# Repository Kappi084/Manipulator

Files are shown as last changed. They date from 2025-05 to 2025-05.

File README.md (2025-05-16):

# Project Background
This project was developed as part of a school project at KTLA (6/7KBMB 2024/25) — a technical school specializing in Mechanical Engineering & Automation Technology.

The manipulator serves as a platform for mechanical engineering students to focus on:

- Learning and applying mechanical design principles
- Improving skills in statics, kinematics, and CAD modeling
- Collaborating across disciplines (mechanical + software)

By separating the complexity of motion programming from the mechanical design, the project allows students to dive deeper into the core engineering concepts without getting blocked by the electronics or software side.

The challenge was to create a universal manipulator platform that can be used for various motion-based systems. T
To solve this, the idea was to build a modular, easy-to-use motion control system — both electrical and in software.

Design Philosophy
The goal of this project was to create a system that is:

✅ Affordable
  Using standard components and easy-to-source materials.
  
✅ Simple to assemble
  Clear CAD files and pre-configured print settings make the system easy to build.
  
✅ Flexible and reusable
  Designed to work across different types of motion systems (e.g., CoreXY, Cartesian, SCARA) with minimal changes.
  
✅ Beginner-friendly software integration
  The controller is programmed in a way that someone without prior coding experience can:

⚙️ Note: The system must be calibrated and configured first. After that, the software can be extended or customized with basic programming skills.

⚙️ Extendable for advanced users
  With just a bit more programming knowledge, the control library can be easily adapted for:

Future Ideas:
- Different kinematics (CoreXY, Delta, etc.)
- External control via digital/analog inputs and outputs
- Different Controller

# Manipulator Overview
This Github-Page is splitted in 3 parts:
- Mecanic
- Electric
- Software

The manipulator shown below features a working range of approximately 250 mm in the X-axis and 750 mm in the Y-axis.

We have implemented a CoreXY kinematic system for this build. CoreXY is a motion architecture commonly used in high-performance 2D positioning systems (e.g., 3D printers, CNC machines) due to its speed, precision, and mechanical efficiency. A detailed describtion you can find in the CAD folder.

Schnittstellenbeschreibung-Kinematic drawio

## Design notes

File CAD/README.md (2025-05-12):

# Mechanical Design (CAD)
This section explains how the manipulator is built and the reasons behind the mechanical design decisions.

If you want to build your own version or take inspiration from this project, all CAD files are available directly on this GitHub repository.
For 3D printing, all relevant STL files — including recommended printer profiles — are also published on MakerWorld:

🔗 MakerWorld – Project Files

# Why CoreXY?
CoreXY offers several advantages compared to traditional Cartesian setups:

- Lightweight X-axis assembly Since both stepper motors are stationary, only the toolhead moves, which significantly reduces the moving mass and allows for faster acceleration.

- High-speed movement The reduced inertia of the moving parts enables rapid and precise movement, ideal for applications requiring speed and accuracy.

- Sturdy and space-efficient design CoreXY allows the motors to be placed on the frame, improving rigidity and making the design more compact.

- Popular and well-documented CoreXY is widely adopted and supported by many firmware platforms like Klipper and Marlin.

🔗 Learn more about CoreXY here: https://corexy.com


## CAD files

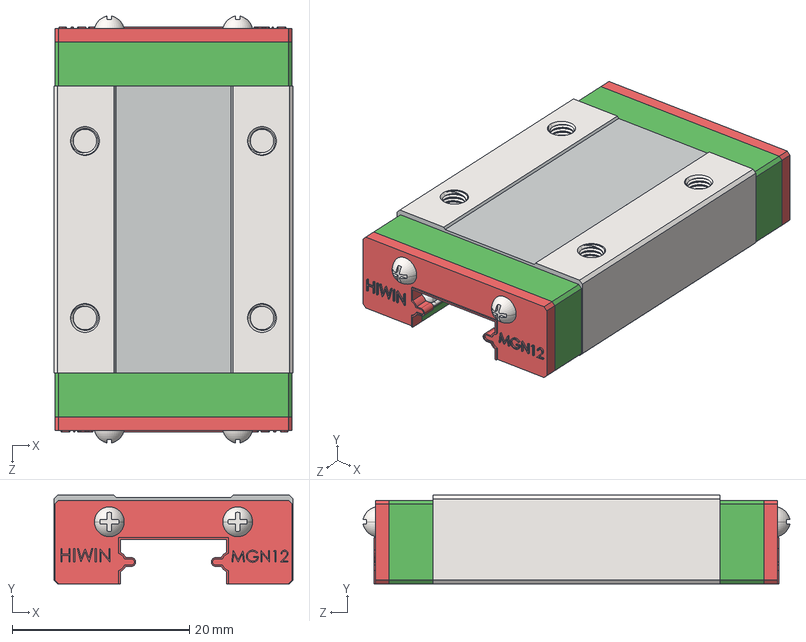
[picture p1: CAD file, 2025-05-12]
CAD/01_StandaradParts/Linear-Rail/Sledge/MGN12H.STEP
27.0 x 10.0 x 48.2 mm
MGN12H_Body
MGN12H_EndCap x 2
MGN12H_Seal x 2
MGN12H_Cage x 2
MGN12H_Ball x 34

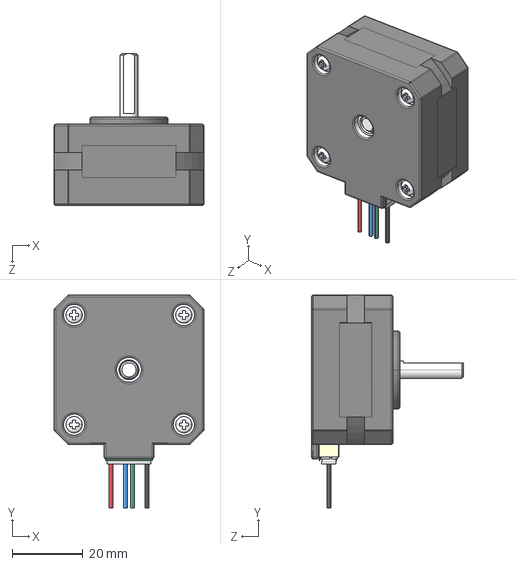
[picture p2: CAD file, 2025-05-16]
CAD/01_StandaradParts/Motor/17HE08-1004S.STEP
42.3 x 60.2 x 43.0 mm

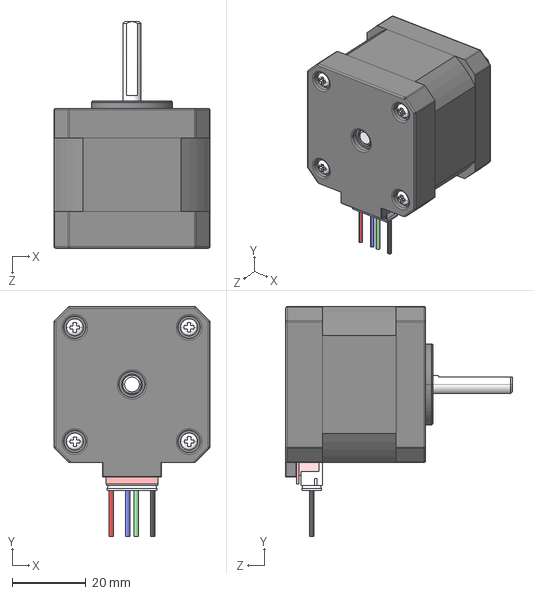
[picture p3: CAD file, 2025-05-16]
CAD/01_StandaradParts/Motor/17HE15-1504S.STEP
42.3 x 62.4 x 61.5 mm

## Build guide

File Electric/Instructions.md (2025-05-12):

# Wiring Overview
The following image shows the wiring layout for the controller. This section explains the design decisions and provides tips to help you replicate the setup reliably.

Design Choices & Best Practices
- Twisted Pair Wiring
  To improve signal stability and reduce electromagnetic interference (EMI), twisted pair wiring is used for:
  
  Stepper motor connections
  
  Serial communication lines (e.g., CAN or RS485)
  
  ⚠️ Important: Make sure to twist the correct pairs on stepper motors (typically A+ with A–, B+ with B–). Incorrect pairing can cause malfunction or motor failure.
  
  Optional upgrade: For improved shielding, consider using high-quality cables with built-in twisted pairs and shielding (e.g., repurposed Ethernet or USB cables).

- 4-Pin & 6-Pin Connectors
  To keep the build cost-efficient, only 4-pin and 6-pin connectors are used:

  6-pin connectors are used for the serial bus, which allows hardwiring of the emergency stop.

  4-pin connectors are used for servos and endstops.

  ⚠️ Attention: Since multiple components share similar 4-pin connectors, always double-check wiring before powering on to avoid accidental damage or miscommunication.

Schnittstellenbeschreibung-Verkabelung Controller drawio

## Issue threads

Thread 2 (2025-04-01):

Neu Verkabelung

Kappi084, 2025-04-01:
- Es wurde leider beim Löten der Motorkabel nicht auf die Farben geachtet.
- Bei dem Verbindungskabel wurde die Verlängerung spiegelverkehrt angelötet

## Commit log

2025-04-01 Create Motion.h
    Erstellen des Headerfiles
2025-04-01 Create Motion.cpp
    Erstellen des .Source-Files
2025-04-24 Create Calibration
